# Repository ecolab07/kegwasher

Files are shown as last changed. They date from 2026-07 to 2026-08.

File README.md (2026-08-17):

# Keg Washer — Automatic Keg Cleaning Machine

> 🇫🇷 [Version française](docs/FR/README_FR.md)

An open-source automatic keg washer controller built on Arduino Uno. Cleans stainless steel kegs **without removing the spears**, using hot caustic soda and peracetic acid circulated by a pump through wash heads.

This project is a fork of [vieuxsinge/kegwasher](https://github.com/vieuxsinge/kegwasher) and [Gummy35/kegwasher](https://github.com/Gummy35/kegwasher). Licensed under [GNU GPL v3](LICENSE).

---

## What it does

The machine automates the full keg cleaning sequence:

- Initial drain and rinse
- Detergent circulation (caustic soda at 80 °C, 3 passes)
- Intermediate rinse
- Sanitizer circulation (peracetic acid, 3 passes)
- Final rinse + CO₂ purge and pressurisation

A full wash cycle takes approximately **5 minutes 30 seconds**. The machine can wash **2 kegs simultaneously**.

📷 *[Photo: machine overview]*

---

## Features

- 11 selectable wash programs via rotary encoder menu
- I²C LCD display: mode name, current step, elapsed / total time
- EEPROM persistence of last selected mode across power cycles
- LED heartbeat and buzzer end-of-cycle notification
- Actuator test mode: fires each valve individually for wiring verification
- Emergency stop via contactor (mushroom-head button)

---

## Hardware

| Component | Details |
|---|---|
| Controller | Arduino Uno (ATmega328P) |
| Relay board | 16-channel, active-low, 12 V |
| Solenoid valves | 9 × 12 V |
| Pump | Novax 20B (or equivalent) |
| Heater | 2500 W immersion element |
| Thermostat | STC1000 |
| SSR | 40 A + heatsink + 12 V fan |
| Display | I²C LCD 16×2 |
| Encoder | Rotary encoder (A1/A2) + action button (A3) |

---

## Try it in the browser

A complete Wokwi simulation is available — no hardware required:

**[▶ Open simulation](https://wokwi.com/projects/464738080652364801)**

Solenoid valves are represented by labelled LEDs. The full sketch runs without modification. Note: Wokwi simulates time slower than real speed.

---

## Repository structure

```
/
├── kegwasher.ino               — Arduino firmware (main branch)
├── CHANGELOG.md                — Fork history and change log
├── CONTRIBUTING.md             — How to contribute
├── LICENSE                     — GNU GPL v3
│
├── docs/
│   ├── EN/
│   │   ├── USER_MANUAL.md      — Operating instructions
│   │   ├── README_TECHNICAL.md — Firmware design decisions
│   │   ├── ELECTRONICS_HOWTO.md— Wiring and assembly guide
│   │   ├── MAINTENANCE_GUIDE.md— Maintenance schedule and procedures
│   │   └── GRAFCET_ALL_MODES.md— Actuator sequence diagrams (all modes)
│   └── FR/
│       ├── README_FR.md
│       ├── MANUEL_UTILISATION.md
│       ├── README_TECHNIQUE.md
│       ├── GUIDE_ELECTRONIQUE.md
│       ├── GUIDE_ENTRETIEN.md
│       └── GRAFCET_TOUS_MODES.md
│
├── fritzing/
│   ├── kegwasher.fzz           — Fritzing source file
│   └── kegwasher.png           — Wiring diagram
│
└── Images/                     — Photos and illustrations
```

---

## Documentation

| Document | EN | FR |
|---|---|---|
| User manual | [EN](docs/EN/USER_MANUAL.md) | [FR](docs/FR/MANUEL_UTILISATION.md) |
| Technical README | [EN](docs/EN/README_TECHNICAL.md) | [FR](docs/FR/README_TECHNIQUE.md) |
| Electronics assembly guide | [EN](docs/EN/ELECTRONICS_HOWTO.md) | [FR](docs/FR/GUIDE_ELECTRONIQUE.md) |
| Maintenance guide | [EN](docs/EN/MAINTENANCE_GUIDE.md) | [FR](docs/FR/GUIDE_ENTRETIEN.md) |
| Mode sequence diagrams | [EN](docs/EN/GRAFCET_ALL_MODES.md) | [FR](docs/FR/GRAFCET_TOUS_MODES.md) |

---

## Fork history

| Generation | Author | Contributions |
|---|---|---|
| v1 | [vieuxsinge](https://github.com/vieuxsinge/kegwasher) | Original project: step engine, bitmask model, wash programs, state machine |
| v2 | [Gummy35](https://github.com/Gummy35/kegwasher) | Ordered actuator sequencing, LCD alternating display, new modes, CO₂ pressurisation |
| v3 | [ecolab07](https://github.com/ecolab07/kegwasher) | Test mode, minimal transition logic, timing fixes, type safety, hardware improvements |

See [CHANGELOG.md](CHANGELOG.md) for the full detailed history.

---

## Contributing

See [CONTRIBUTING.md](CONTRIBUTING.md). Issues and pull requests are welcome.

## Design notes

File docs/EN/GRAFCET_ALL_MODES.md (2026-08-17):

# Mode Sequence Diagrams — Keg Washer

One diagram per mode. Left column "Actuators used" (no border, mirrored vertically) + right column "Steps" (normal boxes). Identical repeated cycles are grouped in a subgraph (e.g. "Detergent cycle") rather than duplicated visually in a loop.

Firmware reference: `MODES[]` in `kegwasher.ino`.

> For a description of each mode (use case, when to use it), see the [User Manual](USER_MANUAL.md).

## Table of Contents

1. [Wash + CO2](#1--wash--co2)
2. [Wash without CO2](#2--wash-without-co2)
3. [Detergent only](#3--detergent-only)
4. [CO2](#4--co2)
5. [Sanitization + CO2](#5--sanitization--co2)
6. [Keg drain](#6--keg-drain)
7. [Sanitizer drain](#7--sanitizer-drain)
8. [Detergent drain](#8--detergent-drain)
9. [Sanitizer fill](#9--sanitizer-fill)
10. [Detergent fill](#10--detergent-fill)
11. [Valve test](#11--valve-test)

---

## 1 — Wash + CO2

Source: `STEPS_WASH_KEG_PRESSURIZE` — ≈ 5 min 35

```mermaid
flowchart TD
    subgraph ACTUATORS["Actuators used"]
    direction TD
        A(["Actuators<br/>at rest"])
        B("DRAIN")
        C("PUMP&nbsp;+&nbsp;WATER&nbsp;+&nbsp;DRAIN<br/>AIR&nbsp;+&nbsp;DRAIN")
        D("PUMP&nbsp;+&nbsp;WATER&nbsp;+&nbsp;DRAIN<br/>CO2&nbsp;+&nbsp;DRAIN<br/>CO2")
        E(["Actuators<br/>at rest"])
        subgraph CL["&nbsp;"]
            direction TB
            CL1("PUMP&nbsp;+&nbsp;CLEANER_IN&nbsp;+&nbsp;CLEANER_OUT<br/>AIR&nbsp;+&nbsp;CLEANER_OUT")
            CL2("PUMP&nbsp;+&nbsp;CLEANER_IN&nbsp;+&nbsp;CLEANER_OUT<br/>AIR&nbsp;+&nbsp;CLEANER_OUT")
            CL3("PUMP&nbsp;+&nbsp;CLEANER_IN&nbsp;+&nbsp;CLEANER_OUT<br/>AIR&nbsp;+&nbsp;CLEANER_OUT")
            CL1 ~~~ CL2 ~~~ CL3
        end
        subgraph RI["&nbsp;"]
            direction TB
            RI1("PUMP&nbsp;+&nbsp;WATER&nbsp;+&nbsp;DRAIN<br/>AIR&nbsp;+&nbsp;DRAIN")
            RI2("PUMP&nbsp;+&nbsp;WATER&nbsp;+&nbsp;DRAIN<br/>AIR&nbsp;+&nbsp;DRAIN")
            RI3("PUMP&nbsp;+&nbsp;WATER&nbsp;+&nbsp;DRAIN<br/>AIR&nbsp;+&nbsp;DRAIN")
            RI1 ~~~ RI2 ~~~ RI3
        end
        subgraph SA["&nbsp;"]
            direction TB
            SA1("PUMP&nbsp;+&nbsp;SANITIZER_IN&nbsp;+&nbsp;SANITIZER_OUT<br/>AIR&nbsp;+&nbsp;SANITIZER_OUT")
            SA2("PUMP&nbsp;+&nbsp;SANITIZER_IN&nbsp;+&nbsp;SANITIZER_OUT<br/>AIR&nbsp;+&nbsp;SANITIZER_OUT")
            SA3("PUMP&nbsp;+&nbsp;SANITIZER_IN&nbsp;+&nbsp;SANITIZER_OUT<br/>AIR&nbsp;+&nbsp;SANITIZER_OUT")
            SA1 ~~~ SA2 ~~~ SA3
        end
        A ~~~ |&nbsp;| B ~~~ C
        C ~~~ CL1
        CL3 ~~~ RI1
        RI3 ~~~ SA1
        SA3 ~~~ D
        D ~~~ E
    end
    style ACTUATORS fill:none,stroke:none
    style CL fill:none,stroke:none
    style RI fill:none,stroke:none
    style SA fill:none,stroke:none
    style B fill:none,stroke:none
    style C fill:none,stroke:none
    style D fill:none,stroke:none
    style CL1 fill:none,stroke:none
    style CL2 fill:none,stroke:none
    style CL3 fill:none,stroke:none
    style RI1 fill:none,stroke:none
    style RI2 fill:none,stroke:none
    style RI3 fill:none,stroke:none
    style SA1 fill:none,stroke:none
    style SA2 fill:none,stroke:none
    style SA3 fill:none,stroke:none
    subgraph STEPS["Mode Wash + CO2"]
        direction TB
        Start(["Mode selected<br/>Wash + CO₂"])
        Drain["Drain 10 s"]
        Rinse0["Initial rinse 10 s<br/>Purge 20 s"]
        subgraph CLEAN["Detergent cycle"]
            direction TB
            C1["Detergent 10 s<br/>Purge 15 s"]
            C2["Detergent 10 s<br/>Purge 15 s"]
            C3["Detergent 10 s<br/>Purge 20 s"]
            C1 --> C2 --> C3
        end
        subgraph RINSE["Intermediate rinse"]
            direction TB
            R1["Rinse 3 s<br/>Purge 10 s"]
            R2["Rinse 7 s<br/>Purge 10 s"]
            R3["Rinse 10 s<br/>Purge 20 s"]
            R1 --> R2 --> R3
        end
        subgraph SAN["Sanitization cycle"]
            direction TB
            S1["Sanitizer 10 s<br/>Purge 15 s"]
            S2["Sanitizer 10 s<br/>Purge 15 s"]
            S3["Sanitizer 30 s<br/>Purge 20 s"]
            S1 --> S2 --> S3
        end
        Final["Final rinse 10 s<br/>CO2 purge 30 s<br/>CO2 pressurisation 10 s"]
        End(["Cycle complete<br/>3 beeps"])
        Start -->|Button press| Drain
        Drain --> Rinse0
        Rinse0 --> C1
        C3 --> R1
        R3 --> S1
        S3 --> Final
        Final --> End
    end
```

---

## 2 — Wash without CO2

Source: `STEPS_WASH_KEG` — ≈ 5 min 25

```mermaid
flowchart TD
    subgraph ACTUATORS["Actuators used"]
    direction TD
        A(["Actuators<br/>at rest"])
        B("DRAIN")
        C("PUMP&nbsp;+&nbsp;WATER&nbsp;+&nbsp;DRAIN<br/>AIR&nbsp;+&nbsp;DRAIN")
        D("PUMP&nbsp;+&nbsp;WATER&nbsp;+&nbsp;DRAIN<br/>AIR&nbsp;+&nbsp;DRAIN")
        E(["Actuators<br/>at rest"])
        subgraph CL["&nbsp;"]
            direction TB
            CL1("PUMP&nbsp;+&nbsp;CLEANER_IN&nbsp;+&nbsp;CLEANER_OUT<br/>AIR&nbsp;+&nbsp;CLEANER_OUT")
            CL2("PUMP&nbsp;+&nbsp;CLEANER_IN&nbsp;+&nbsp;CLEANER_OUT<br/>AIR&nbsp;+&nbsp;CLEANER_OUT")
            CL3("PUMP&nbsp;+&nbsp;CLEANER_IN&nbsp;+&nbsp;CLEANER_OUT<br/>AIR&nbsp;+&nbsp;CLEANER_OUT")
            CL1 ~~~ CL2 ~~~ CL3
        end
        subgraph RI["&nbsp;"]
            direction TB
            RI1("PUMP&nbsp;+&nbsp;WATER&nbsp;+&nbsp;DRAIN<br/>AIR&nbsp;+&nbsp;DRAIN")
            RI2("PUMP&nbsp;+&nbsp;WATER&nbsp;+&nbsp;DRAIN<br/>AIR&nbsp;+&nbsp;DRAIN")
            RI3("PUMP&nbsp;+&nbsp;WATER&nbsp;+&nbsp;DRAIN<br/>AIR&nbsp;+&nbsp;DRAIN")
            RI1 ~~~ RI2 ~~~ RI3
        end
        subgraph SA["&nbsp;"]
            direction TB
            SA1("PUMP&nbsp;+&nbsp;SANITIZER_IN&nbsp;+&nbsp;SANITIZER_OUT<br/>AIR&nbsp;+&nbsp;SANITIZER_OUT")
            SA2("PUMP&nbsp;+&nbsp;SANITIZER_IN&nbsp;+&nbsp;SANITIZER_OUT<br/>AIR&nbsp;+&nbsp;SANITIZER_OUT")
            SA3("PUMP&nbsp;+&nbsp;SANITIZER_IN&nbsp;+&nbsp;SANITIZER_OUT<br/>AIR&nbsp;+&nbsp;SANITIZER_OUT")
            SA1 ~~~ SA2 ~~~ SA3
        end
        A ~~~ |&nbsp;| B ~~~ C
        C ~~~ CL1
        CL3 ~~~ RI1
        RI3 ~~~ SA1
        SA3 ~~~ D
        D ~~~ E
    end
    style ACTUATORS fill:none,stroke:none
    style CL fill:none,stroke:none
    style RI fill:none,stroke:none
    style SA fill:none,stroke:none
    style B fill:none,stroke:none
    style C fill:none,stroke:none
    style D fill:none,stroke:none
    style CL1 fill:none,stroke:none
    style CL2 fill:none,stroke:none
    style CL3 fill:none,stroke:none
    style RI1 fill:none,stroke:none
    style RI2 fill:none,stroke:none
    style RI3 fill:none,stroke:none
    style SA1 fill:none,stroke:none
    style SA2 fill:none,stroke:none
    style SA3 fill:none,stroke:none
    subgraph STEPS["Mode Wash without CO2"]
        direction TB
        Start(["Mode selected<br/>Wash without CO₂"])
        Drain["Drain 10 s"]
        Rinse0["Initial rinse 10 s<br/>Purge 20 s"]
        subgraph CLEAN["Detergent cycle"]
            direction TB
            C1["Detergent 10 s<br/>Purge 15 s"]
            C2["Detergent 10 s<br/>Purge 15 s"]
            C3["Detergent 10 s<br/>Purge 20 s"]
            C1 --> C2 --> C3
        end
        subgraph RINSE["Intermediate rinse"]
            direction TB
            R1["Rinse 3 s<br/>Purge 10 s"]
            R2["Rinse 7 s<br/>Purge 10 s"]
            R3["Rinse 10 s<br/>Purge 20 s"]
            R1 --> R2 --> R3
        end
        subgraph SAN["Sanitization cycle"]
            direction TB
            S1["Sanitizer 10 s<br/>Purge 15 s"]
            S2["Sanitizer 10 s<br/>Purge 15 s"]
            S3["Sanitizer 30 s<br/>Purge 20 s"]
            S1 --> S2 --> S3
        end
        Final["Final rinse 10 s<br/>Air purge 30 s"]
        End(["Cycle complete<br/>3 beeps"])
        Start -->|Button press| Drain
        Drain --> Rinse0
        Rinse0 --> C1
        C3 --> R1
        R3 --> S1
        S3 --> Final
        Final --> End
    end
```

---

## 3 — Detergent only

Source: `STEPS_DETER_KEG` — ≈ 3 min 00. No sanitization cycle, no separate final rinse: the intermediate rinse cycle ends the mode directly.

```mermaid
flowchart TD
    subgraph ACTUATORS["Actuators used"]
    direction TD
        A(["Actuators<br/>at rest"])
        B("DRAIN")
        C("PUMP&nbsp;+&nbsp;WATER&nbsp;+&nbsp;DRAIN<br/>AIR&nbsp;+&nbsp;DRAIN")
        E(["Actuators<br/>at rest"])
        subgraph CL["&nbsp;"]
            direction TB
            CL1("PUMP&nbsp;+&nbsp;CLEANER_IN&nbsp;+&nbsp;CLEANER_OUT<br/>AIR&nbsp;+&nbsp;CLEANER_OUT")
            CL2("PUMP&nbsp;+&nbsp;CLEANER_IN&nbsp;+&nbsp;CLEANER_OUT<br/>AIR&nbsp;+&nbsp;CLEANER_OUT")
            CL3("PUMP&nbsp;+&nbsp;CLEANER_IN&nbsp;+&nbsp;CLEANER_OUT<br/>AIR&nbsp;+&nbsp;CLEANER_OUT")
            CL1 ~~~ CL2 ~~~ CL3
        end
        subgraph RI["&nbsp;"]
            direction TB
            RI1("PUMP&nbsp;+&nbsp;WATER&nbsp;+&nbsp;DRAIN<br/>AIR&nbsp;+&nbsp;DRAIN")
            RI2("PUMP&nbsp;+&nbsp;WATER&nbsp;+&nbsp;DRAIN<br/>AIR&nbsp;+&nbsp;DRAIN")
            RI3("PUMP&nbsp;+&nbsp;WATER&nbsp;+&nbsp;DRAIN<br/>AIR&nbsp;+&nbsp;DRAIN")
            RI1 ~~~ RI2 ~~~ RI3
        end
        A ~~~ |&nbsp;| B ~~~ C
        C ~~~ CL1
        CL3 ~~~ RI1
        RI3 ~~~ E
    end
    style ACTUATORS fill:none,stroke:none
    style CL fill:none,stroke:none
    style RI fill:none,stroke:none
    style B fill:none,stroke:none
    style C fill:none,stroke:none
    style CL1 fill:none,stroke:none
    style CL2 fill:none,stroke:none
    style CL3 fill:none,stroke:none
    style RI1 fill:none,stroke:none
    style RI2 fill:none,stroke:none
    style RI3 fill:none,stroke:none
    subgraph STEPS["Mode Detergent only"]
        direction TB
        Start(["Mode selected<br/>Detergent only"])
        Drain["Drain 10 s"]
        Rinse0["Initial rinse 10 s<br/>Purge 20 s"]
        subgraph CLEAN["Detergent cycle"]
            direction TB
            C1["Detergent 10 s<br/>Purge 15 s"]
            C2["Detergent 10 s<br/>Purge 15 s"]
            C3["Detergent 10 s<br/>Purge 20 s"]
            C1 --> C2 --> C3
        end
        subgraph RINSE["Intermediate rinse"]
            direction TB
            R1["Rinse 3 s<br/>Purge 10 s"]
            R2["Rinse 7 s<br/>Purge 10 s"]
            R3["Rinse 10 s<br/>Purge 20 s"]
            R1 --> R2 --> R3
        end
        End(["Cycle complete<br/>3 beeps"])
        Start -->|Button press| Drain
        Drain --> Rinse0
        Rinse0 --> C1
        C3 --> R1
        R3 --> End
    end
```

---

## 4 — CO2

Source: `STEPS_KEG_PRESSURIZE` — 50 s. Shortest mode, purely linear.

```mermaid
flowchart TD
    subgraph ACTUATORS["Actuators used"]
    direction TD
        A(["Actuators<br/>at rest"])
        B("DRAIN")
        C("CO2&nbsp;+&nbsp;DRAIN")
        D("CO2")
        E(["Actuators<br/>at rest"])
        A ~~~ |&nbsp;| B ~~~ C ~~~ D ~~~ E
    end
    style ACTUATORS fill:none,stroke:none
    style B fill:none,stroke:none
    style C fill:none,stroke:none
    style D fill:none,stroke:none
    subgraph STEPS["Mode CO2"]
        direction TB
        Start(["Mode selected<br/>CO2"])
        Drain["Drain 10 s"]
        Purge["CO2 purge 30 s"]
        Press["CO2 pressurisation 10 s"]
        End(["Cycle complete<br/>3 beeps"])
        Start -->|Button press| Drain
        Drain --> Purge
        Purge --> Press
        Press --> End
    end
```

---

## 5 — Sanitization + CO2

Source: `STEPS_SANITIZE_KEG_PRESSURIZE` — ≈ 3 min 10

```mermaid
flowchart TD
    subgraph ACTUATORS["Actuators used"]
    direction TD
        A(["Actuators<br/>at rest"])
        B("DRAIN")
        C("PUMP&nbsp;+&nbsp;WATER&nbsp;+&nbsp;DRAIN<br/>AIR&nbsp;+&nbsp;DRAIN")
        D("PUMP&nbsp;+&nbsp;WATER&nbsp;+&nbsp;DRAIN<br/>CO2&nbsp;+&nbsp;DRAIN<br/>CO2")
        E(["Actuators<br/>at rest"])
        subgraph SA["&nbsp;"]
            direction TB
            SA1("PUMP&nbsp;+&nbsp;SANITIZER_IN&nbsp;+&nbsp;SANITIZER_OUT<br/>AIR&nbsp;+&nbsp;SANITIZER_OUT")
            SA2("PUMP&nbsp;+&nbsp;SANITIZER_IN&nbsp;+&nbsp;SANITIZER_OUT<br/>AIR&nbsp;+&nbsp;SANITIZER_OUT")
            SA3("PUMP&nbsp;+&nbsp;SANITIZER_IN&nbsp;+&nbsp;SANITIZER_OUT<br/>AIR&nbsp;+&nbsp;SANITIZER_OUT")
            SA1 ~~~ SA2 ~~~ SA3
        end
        A ~~~ |&nbsp;| B ~~~ C
        C ~~~ SA1
        SA3 ~~~ D
        D ~~~ E
    end
    style ACTUATORS fill:none,stroke:none
    style SA fill:none,stroke:none
    style B fill:none,stroke:none
    style C fill:none,stroke:none
    style D fill:none,stroke:none
    style SA1 fill:none,stroke:none
    style SA2 fill:none,stroke:none
    style SA3 fill:none,stroke:none
    subgraph STEPS["Mode Sanitization + CO2"]
        direction TB
        Start(["Mode selected<br/>Sanitiz. + CO₂"])
        Drain["Drain 10 s"]
        Rinse0["Initial rinse 10 s<br/>Purge 20 s"]
        subgraph SAN["Sanitization cycle"]
            direction TB
            S1["Sanitizer 10 s<br/>Purge 15 s"]
            S2["Sanitizer 10 s<br/>Purge 15 s"]
            S3["Sanitizer 30 s<br/>Purge 20 s"]
            S1 --> S2 --> S3
        end
        Final["Final rinse 10 s<br/>CO2 purge 30 s<br/>CO2 pressurisation 10 s"]
        End(["Cycle complete<br/>3 beeps"])
        Start -->|Button press| Drain
        Drain --> Rinse0
        Rinse0 --> S1
        S3 --> Final
        Final --> End
    end
```

---

## 6 — Keg drain

Source: `STEPS_DRAIN_KEG` — 70 s

```mermaid
flowchart TD
    subgraph ACTUATORS["Actuators used"]
    direction TD
        A(["Actuators<br/>at rest"])
        B("DRAIN")
        C("AIR&nbsp;+&nbsp;DRAIN")
        E(["Actuators<br/>at rest"])
        A ~~~ |&nbsp;| B ~~~ C ~~~ E
    end
    style ACTUATORS fill:none,stroke:none
    style B fill:none,stroke:none
    style C fill:none,stroke:none
    subgraph STEPS["Mode Keg drain"]
        direction TB
        Start(["Mode selected<br/>Keg drain"])
        Drain["Drain 10 s"]
        Purge["Air purge 60 s"]
        End(["Cycle complete<br/>3 beeps"])
        Start -->|Button press| Drain
        Drain --> Purge
        Purge --> End
    end
```

---

## 7 — Sanitizer drain

Source: `STEPS_DRAIN_SANITIZER` — 200 s, single step.

```mermaid
flowchart TD
    subgraph ACTUATORS["Actuators used"]
    direction TD
        A(["Actuators<br/>at rest"])
        B("PUMP&nbsp;+&nbsp;SANITIZER_IN&nbsp;+&nbsp;DRAIN")
        E(["Actuators<br/>at rest"])
        A ~~~ |&nbsp;| B ~~~ E
    end
    style ACTUATORS fill:none,stroke:none
    style B fill:none,stroke:none
    subgraph STEPS["Mode Sanitizer drain"]
        direction TB
        Start(["Mode selected<br/>Sanitizer drain"])
        Drain["Drain sanitizer tank<br/>200 s"]
        End(["Cycle complete<br/>3 beeps"])
        Start -->|Button press| Drain
        Drain --> End
    end
```

---

## 8 — Detergent drain

Source: `STEPS_DRAIN_CLEANER` — 200 s, single step.

```mermaid
flowchart TD
    subgraph ACTUATORS["Actuators used"]
    direction TD
        A(["Actuators<br/>at rest"])
        B("PUMP&nbsp;+&nbsp;CLEANER_IN&nbsp;+&nbsp;DRAIN")
        E(["Actuators<br/>at rest"])
        A ~~~ |&nbsp;| B ~~~ E
    end
    style ACTUATORS fill:none,stroke:none
    style B fill:none,stroke:none
    subgraph STEPS["Mode Detergent drain"]
        direction TB
        Start(["Mode selected<br/>Detergent drain"])
        Drain["Drain detergent tank<br/>200 s"]
        End(["Cycle complete<br/>3 beeps"])
        Start -->|Button press| Drain
        Drain --> End
    end
```

---

## 9 — Sanitizer fill

Source: `STEPS_FILL_SANITIZER` — 120 s, single step.

```mermaid
flowchart TD
    subgraph ACTUATORS["Actuators used"]
    direction TD
        A(["Actuators<br/>at rest"])
        B("PUMP&nbsp;+&nbsp;SANITIZER_OUT&nbsp;+&nbsp;WATER")
        E(["Actuators<br/>at rest"])
        A ~~~ |&nbsp;| B ~~~ E
    end
    style ACTUATORS fill:none,stroke:none
    style B fill:none,stroke:none
    subgraph STEPS["Mode Sanitizer fill"]
        direction TB
        Start(["Mode selected<br/>Sanitizer fill"])
        Fill["Fill sanitizer tank<br/>120 s"]
        End(["Cycle complete<br/>3 beeps"])
        Start -->|Button press| Fill
        Fill --> End
    end
```

---

## 10 — Detergent fill

Source: `STEPS_FILL_CLEANER` — 120 s, single step.

```mermaid
flowchart TD
    subgraph ACTUATORS["Actuators used"]
    direction TD
        A(["Actuators<br/>at rest"])
        B("PUMP&nbsp;+&nbsp;CLEANER_OUT&nbsp;+&nbsp;WATER")
        E(["Actuators<br/>at rest"])
        A ~~~ |&nbsp;| B ~~~ E
    end
    style ACTUATORS fill:none,stroke:none
    style B fill:none,stroke:none
    subgraph STEPS["Mode Detergent fill"]
        direction TB
        Start(["Mode selected<br/>Detergent fill"])
        Fill["Fill detergent tank<br/>120 s"]
        End(["Cycle complete<br/>3 beeps"])
        Start -->|Button press| Fill
        Fill --> End
    end
```

---

## 11 — Valve test

Source: `STEPS_TEST_ACTUATORS` — 24 s.

**Template exception:** this mode does not follow the two-column layout. Each step activates a *different* actuator (no repeated identical block), so the "Actuators" column would be redundant with the step name itself. Single-column diagram, purely sequential.

```mermaid
flowchart TD
    subgraph STEPS["Mode Valve test"]
        direction TB
        Start(["Mode selected<br/>Valve test"])
        Warn{{"Confirmation:<br/>tanks empty?<br/>5 s"}}
        T1["Sanitizer return valve<br/>1 s"]
        T2["Drain valve<br/>1 s"]
        T3["Cleaner return valve<br/>1 s"]
        T4["Air valve<br/>1 s"]
        T5["CO2 valve<br/>1 s"]
        T6["Sanitizer inlet valve<br/>1 s"]
        T7["Water valve<br/>1 s"]
        T8["Cleaner inlet valve<br/>1 s"]
        T9["Pump<br/>1 s"]
        End(["Cycle complete<br/>3 beeps"])
        Start -->|Button press| Warn
        Warn -->|1 s gap| T1
        T1 -->|1 s gap| T2
        T2 -->|1 s gap| T3
        T3 -->|1 s gap| T4
        T4 -->|1 s gap| T5
        T5 -->|1 s gap| T6
        T6 -->|1 s gap| T7
        T7 -->|1 s gap| T8
        T8 -->|1 s gap| T9
        T9 --> End
    end
```

**Note valid for all 11 modes:** pressing the button during execution cancels the running sequence (valves close, 1 beep, return to selection screen) — not shown on each diagram to avoid clutter.

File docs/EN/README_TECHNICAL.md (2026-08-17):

# kegwasher — Technical README

> This project is a fork of [vieuxsinge/kegwasher](https://github.com/vieuxsinge/kegwasher)
> and [Gummy35/kegwasher](https://github.com/Gummy35/kegwasher).
> License: GNU GPL v3.

This document covers the technical design decisions made across the three generations of the project. For usage instructions, see [USER_MANUAL.md](USER_MANUAL.md).

---

## Table of Contents

1. [Architecture overview](#1-architecture-overview)
2. [Step-based sequence engine](#2-step-based-sequence-engine)
3. [Actuator control model](#3-actuator-control-model)
4. [Ordered open/close sequencing — Gummy35 + Ecolab07](#4-ordered-openclose-sequencing--gummy35--ecolab07)
5. [Pin pre-initialisation to HIGH — Ecolab07](#5-pin-pre-initialisation-to-high--ecolab07)
6. [State machine](#6-state-machine)
7. [LCD display: alternating step and mode labels — Gummy35 + Ecolab07](#7-lcd-display-alternating-step-and-mode-labels--gummy35--ecolab07)
8. [Rotary encoder: negative value guard — Ecolab07](#8-rotary-encoder-negative-value-guard--ecolab07)
9. [EEPROM persistence of selected mode](#9-eeprom-persistence-of-selected-mode)
10. [Actuator test mode — Ecolab07](#10-actuator-test-mode--ecolab07)
11. [Wash mode catalogue](#11-wash-mode-catalogue)
12. [Hardware notes](#12-hardware-notes)
13. [Dependencies](#13-dependencies)
14. [Wokwi simulation](#14-wokwi-simulation)
15. [Wiring diagram (Fritzing)](#15-wiring-diagram-fritzing)
16. [Known limitations and future work](#16-known-limitations-and-future-work)

---

## 1. Architecture overview

The firmware is a single `.ino` file structured around three independent layers:

```
┌─────────────────────────────────┐
│  Mode table  (MODES[])          │  Named modes → step arrays
├─────────────────────────────────┤
│  Sequence engine                │  Steps → actuator configs + timing
├─────────────────────────────────┤
│  Actuator control layer         │  Bitmasks → individual GPIO writes
└─────────────────────────────────┘
```

Adding a new wash program requires only a new `step_t` array and one entry in `MODES[]`. No control logic needs to change.

---

## 2. Step-based sequence engine

Each wash program is expressed as an array of `step_t` structs:

```c
typedef struct step_s {
  unsigned int  config;   // bitmask of actuators to activate
  unsigned long duration; // how long to hold this configuration (seconds)
} step_t;
```

The array is terminated by the sentinel value `{CONFIG_END, 0}` (where `CONFIG_END == 0`), which is how `run_update()` detects end-of-sequence without needing a length parameter.

At runtime, `step_set(index)` applies the valve configuration via `controls_set()` (blocking), then records `step_start_time` after the transitions complete. `run_update()` is called on every `loop()` iteration and advances to the next step as soon as `seconds() - step_start_time >= step.duration`.

Recording `step_start_time` after the transitions ensures each step's declared duration is measured from when the valves are actually in their target state, not from before the blocking delay. The same principle applies to `mode_start_time`, which is recorded after `step_set(0)` in `run()`.

Using wall-clock seconds (via `millis() / 1000`) rather than a counter makes step timing independent of loop execution time. All time variables use `unsigned long` (32 bits on AVR), consistent with `millis()` and safe from the 16-bit overflow that would affect `int` after ~9 hours.

---

## 3. Actuator control model

Each of the 9 physical outputs is assigned a unique power-of-two bit:

```c
#define CTRL_WATER          0b000000001
#define CTRL_CLEANER_IN     0b000000010
#define CTRL_SANITIZER_IN   0b000000100
#define CTRL_AIR            0b000001000
#define CTRL_CO2            0b000010000
#define CTRL_DRAIN          0b000100000
#define CTRL_CLEANER_OUT    0b001000000
#define CTRL_SANITIZER_OUT  0b010000000
#define CTRL_PUMP           0b100000000
```

Composite configurations for the wash sequences are built by OR-ing individual bits:

```c
#define CONFIG_CLEAN  (CTRL_PUMP + CTRL_CLEANER_IN + CTRL_CLEANER_OUT)
```

This gives a compact, readable, and easily extensible representation. Adding a 10th actuator only requires a new bit and a new pin — no structural changes.

The test mode deliberately uses raw `CTRL_*` bits (one actuator at a time) rather than composite `CONFIG_*` values, which is what makes it useful for diagnosing individual valve behaviour.

---

## 4. Ordered open/close sequencing — *Gummy35* + *Ecolab07*

The original firmware switched all actuators simultaneously with no delay between them, using raw `HIGH`/`LOW` values. Gummy35 refactored `controls_set_state()` entirely, introducing three changes.

**Named logic constants** replacing raw `HIGH`/`LOW`:
```c
#define VALVE_CLOSE HIGH
#define VALVE_OPEN  LOW
```
This makes the active-low relay logic explicit at every call site.

**Per-direction ordering** — actuators are now opened and closed in a carefully chosen order:

Closing order (pressure sources first, then outputs): pump → water/CO₂/air → liquid inlets → return paths → drain (last, so residual pressure can escape).

Opening order (clear path before pressure): drain/returns → liquid inlets → pump (draws liquid, reducing inlet pressure) → air → CO₂ → water (last — pump backpressure prevents back-flow into tanks).

This ordering prevents pressure spikes trapping liquid in lines when closing, water or chemicals back-flowing into CO₂ or air lines when opening, and pump cavitation.

**Inter-actuator delay on closing** increased from 0 ms to 200 ms, matching the opening delay already present in the original:

```c
// before (Vieuxsinge)
controls_set_state(~config, HIGH, 0);   // close: no delay
controls_set_state(config,  LOW,  200); // open:  200 ms

// after (Gummy35)
controls_set_state(~config, VALVE_CLOSE, 200); // close: 200 ms
controls_set_state(config,  VALVE_OPEN,  200); // open:  200 ms
```

**Also changed by Gummy35**: `CONFIG_FILL_SANITIZER` and `CONFIG_FILL_CLEANER` had `CTRL_PUMP` removed (filling by mains pressure only). This was reverted in the ecolab07 fork — the pump is needed to circulate water through the keg and back into the tank via the return valves (`CTRL_SANITIZER_OUT` / `CTRL_CLEANER_OUT`). The inlet valves (`CTRL_SANITIZER_IN` / `CTRL_CLEANER_IN`) are oriented in the wrong direction for this flow path and are not used during filling.

**Ecolab07 — minimal transition logic**: `controls_set_state()` was split into `close_actuators()` and `open_actuators()`, and `controls_set()` was rewritten to only touch actuators that actually change state:

```c
unsigned int previous_config = 0;  // tracks the active configuration

void controls_set(unsigned int config)
{
  unsigned int to_close = previous_config & ~config;
  unsigned int to_open  = config & ~previous_config;

  close_actuators(to_close);
  open_actuators(to_open);

  previous_config = config;
}
```

`previous_config & ~config` isolates actuators that were open and are no longer needed. `config & ~previous_config` isolates actuators that are needed and were not already open. Actuators that appear in both the old and new configuration are not touched. This has three benefits:

- **Inrush current**: only the relays that actually change state switch, never all 9 simultaneously.
- **Timing accuracy**: the 200 ms delay only applies to actuators that move, so transitions between similar configurations (e.g. `CONFIG_CLEAN` → `CONFIG_CLEAN_PURGE`, which share `CTRL_CLEANER_OUT`) are faster.
- **`CONFIG_WARNING` / `CONFIG_WAIT` safety by design**: these pseudo-configs have bits 10 and 11 set, outside the 9-bit actuator range. `to_close` and `to_open` mask these bits out naturally — no actuator is ever triggered, regardless of what `previous_config` held.

---

## 5. Pin pre-initialisation to HIGH — *Ecolab07*

The relay board uses **active-low logic**: a LOW signal on a control pin energises the relay and opens the valve. The Arduino's GPIO pins default to a high-impedance input state at power-up, which the relay board pulls LOW — briefly energising all relays before `pinMode(OUTPUT)` is called in `setup()`.

This causes an uncontrolled inrush current spike (all 9 relays switching simultaneously) and, more critically, a momentary opening of all valves.

The fix is to write `HIGH` to each pin *before* calling `pinMode()`:

```c
// Pre-drive HIGH before configuring as output to prevent
// the brief LOW glitch that would otherwise energise all relays at power-up
digitalWrite(PIN_VALVE_AIR, HIGH);
// ... all other valve and pump pins ...
pinMode(PIN_VALVE_AIR, OUTPUT);
// ...
```

On AVR-based Arduinos, `digitalWrite()` on a pin that is still in input mode writes to the pull-up register, which does not produce a LOW glitch. The transition to `OUTPUT` mode therefore starts from a committed HIGH level, keeping all relays de-energised.

---

## 6. State machine

The main loop dispatches on a `state_t` enum:

```
STATE_SELECT → STATE_SELECT_UPDATE ──────────────────────┐
                     │ (button press)                     │
                     ▼                                    │
               STATE_RUN                                  │
                     │                                    │
                     ▼                                    │
             STATE_RUN_UPDATE ──── (button press) ──► STATE_CANCEL ─┐
                     │ (CONFIG_END)                                  │
                     ▼                                               │
             STATE_TERMINATE ──────────────────────────────────────►┘
                                                         (all → STATE_SELECT)
```

Each state has a dedicated handler function. Transitions are written as assignments to the global `state` variable, which the next `loop()` iteration will dispatch on. This keeps each handler small and single-purpose.

---

## 7. LCD display: alternating step and mode labels — *Gummy35* + *Ecolab07*

During a running cycle, line 1 of the LCD alternates between two pieces of information on a `LED_BLINK_PERIOD` (2 s) cadence:

- **First half of period**: the current step label — e.g. `Detergent`, `Purge air`
- **Second half of period**: the mode name — e.g. `Lavage + CO2`

The LED blinks in sync with this alternation, providing a visible heartbeat that also confirms the Arduino is still running.

```c
if( mode_running_time % LED_BLINK_PERIOD < LED_BLINK_PERIOD/2 ) {
    digitalWrite(PIN_LED, HIGH);
    lcd.setCursor(0, 0);
    lcd_printf(resolve_label(MODES[mode].steps[step].config));
}
else {
    digitalWrite(PIN_LED, LOW);
    lcd.setCursor(0, 0);
    lcd_printf(MODES[mode].name);
}
```

**Gummy35** introduced this alternating display and resolved labels via a `config_label` global variable written inside `controls_set_state()`. **Ecolab07** replaced this with `resolve_label()`, a pure function that returns a `const char*` to a Flash literal with no side effects. The global variable is eliminated — the label is resolved on demand directly from the current step's config.

---

## 8. Rotary encoder: negative value guard — *Ecolab07*

The `RotaryEncoder` library returns a signed integer position that decrements below zero when the encoder is turned counter-clockwise past position 0. A naive modulo operation in C produces negative results for negative operands (the sign follows the dividend), which would result in an invalid array index into `MODES[]`.

**First approach** — adding `MODES_NUMBER` before the modulo:
```c
new_mode = (pos + MODES_NUMBER) % MODES_NUMBER;
```
This works correctly for one full counter-clockwise wrap (e.g. `pos = -3` with `MODES_NUMBER = 11` gives `8` ✅), but silently fails when `pos` is more negative than `-MODES_NUMBER` (e.g. `pos = -14` gives `-3` ❌, because `(-14 + 11) % 11 = -3` in C).

**Current approach** — double modulo:
```c
new_mode = ((pos % MODES_NUMBER) + MODES_NUMBER) % MODES_NUMBER;
```
`pos % MODES_NUMBER` first reduces any value into `(-MODES_NUMBER, MODES_NUMBER)`, then adding `MODES_NUMBER` makes it positive, and the final `% MODES_NUMBER` brings it back into `[0, MODES_NUMBER - 1]`. This is correct for any value of `pos`, regardless of how far counter-clockwise the encoder has been turned.

---

## 9. EEPROM persistence of selected mode

The index of the last selected mode is written to EEPROM address `0` when a cycle is launched (only if the value has changed, to limit write wear):

```c
int saved_mode = EEPROM.read(EEPROM_ADDRESS_MODE);
if( mode != saved_mode ) {
    EEPROM.write(EEPROM_ADDRESS_MODE, mode);
}
```

On power-up, the stored value is read and clamped to the valid range:

```c
mode = constrain(mode, 0, MODES_NUMBER - 1);
```

The clamp handles the case where the EEPROM contains `0xFF` (erased state) or a stale index from a firmware version with fewer modes.

---

## 10. Actuator test mode — *Ecolab07*

The test mode fires each of the 9 actuators individually for 1 second, in the physical order of the relay board, with a 1-second idle gap between each pulse.

**Design intent**: the test mode is implemented entirely as a `step_t` array (`STEPS_TEST_ACTUATORS`), using the same sequence engine as all other modes. No special-case code was added to the control layer.

Each step uses a raw `CTRL_*` bit rather than a composite `CONFIG_*` value, so exactly one relay clicks per step. This makes it straightforward to verify each valve by ear or by watching the circuit.

Two special pseudo-configurations are introduced exclusively for this mode:

| Constant | Bit | Role |
|---|---|---|
| `CONFIG_WARNING` | bit 10 | Displays a safety prompt (`Cuves vides ?`) before the first relay fires. No actuator is activated. |
| `CONFIG_WAIT` | bit 11 | Idle step between pulses: `controls_set(CONFIG_WAIT)` closes everything (bits 0–9 are all zero in the mask), producing a clean off state between each individual actuation. |

Both bits are outside the 9-bit range of real actuator bits, so they cannot accidentally overlap with any physical output.

---

## 11. Wash mode catalogue

| Mode | Array | Duration | Gummy35 | Ecolab07 |
|---|---|---|---|---|
| `Lavage + CO2` | `STEPS_WASH_KEG_PRESSURIZE` | 330 s | ✅ CO₂ step | |
| `Lavage sans CO2` | `STEPS_WASH_KEG` | 320 s | | |
| `Detergent seul` | `STEPS_DETER_KEG` | 180 s | ✅ added | |
| `CO2` | `STEPS_KEG_PRESSURIZE` | 50 s | ✅ added | |
| `Desinf. + CO2` | `STEPS_SANITIZE_KEG_PRESSURIZE` | 190 s | ✅ added | |
| `Vidange fut` | `STEPS_DRAIN_KEG` | 70 s | | |
| `Vidange desinf.` | `STEPS_DRAIN_SANITIZER` | 200 s | | |
| `Vidange deter.` | `STEPS_DRAIN_CLEANER` | 200 s | | |
| `Rempl. desinf.` | `STEPS_FILL_SANITIZER` | 120 s | | |
| `Rempl. deter.` | `STEPS_FILL_CLEANER` | 120 s | | |
| `Test vannes` | `STEPS_TEST_ACTUATORS` | 22 s | | ✅ added |

---

## 12. Hardware notes

### Relay board — active-low logic
The 16-channel relay board uses active-low inputs. All control pins are pre-driven HIGH at boot (see §5) to prevent unintended actuation.

### Flyback diode protection
Solenoid valves are inductive loads. Without protection, the back-EMF spike when a valve de-energises can destroy relay contacts. A 1N4148 flyback diode is placed across each valve terminal, as close to the relay output as possible.

### SSR for the detergent heater
The immersion heater in the detergent tank is switched by a 40 A solid-state relay (SSR), controlled by the STC1000 thermostat. The original 3500 W element was downrated to **2500 W** to avoid tripping the circuit breaker on shared circuits — heating is slower but stays within the breaker's sustained current rating. The SSR is fitted with a **heatsink and a 12 V cooling fan** (Ecolab07 improvement) to prevent thermal runaway during long heating sessions.

### Emergency stop via contactor
The original design connected the emergency stop button directly in the control circuit. Ecolab07 replaced this with a **contactor** driven by the mushroom-head button, so the button switches only a low-current coil rather than the full load current of the machine. This improves button longevity and is safer in a wet environment.

### Arduino terminal screw shield
Ecolab07 added a **terminal screw shield** on top of the Arduino, fitted with an integrated prototyping area. This allows:
- the LED current-limiting resistor to be mounted cleanly on the board
- all external cables to be terminated on screw terminals rather than Dupont connectors, improving mechanical reliability in an environment subject to vibration and moisture.

### Relay output bus bars
Ecolab07 added **bus bar rails** on the relay output side to simplify solenoid valve wiring. Each bus bar groups the common 12 V return wire for a set of valves, reducing point-to-point wiring complexity and making the enclosure easier to read.

### Component labelling
All components inside the enclosure are identified by adhesive labels. This makes fault-finding and maintenance accessible without referring to a wiring diagram.

---

## 13. Dependencies

| Library | Version tested | Purpose |
|---|---|---|
| `Bounce2` | any | Button debouncing |
| `LiquidCrystal_I2C` | 1.1.2 | I²C LCD driver |
| `RotaryEncoder` | any | Rotary encoder reading |

**`LiquidCrystal_I2C`** — authored by Frank de Brabander, maintained by Marco Schwartz, hosted at [github.com/johnrickman/LiquidCrystal_I2C](https://github.com/johnrickman/LiquidCrystal_I2C). Install via the Arduino IDE Library Manager by searching for `LiquidCrystal I2C` — this installs version 1.1.2, which is the version used in this project and works without modification. There are several other forks of this library under similar names; using the wrong one may cause compilation errors or incorrect display behaviour.

---

## 14. Wokwi simulation

A complete circuit simulation is available at:
**[https://wokwi.com/projects/464738080652364801](https://wokwi.com/projects/464738080652364801)**

The simulation includes the Arduino Uno, I²C LCD display, relay board (active-low logic), status LED, buzzer, rotary encoder, and action button. Solenoid valves are represented by LEDs labelled with the corresponding valve name, allowing visual verification of each actuation sequence.

The full sketch runs without modification in the simulator.

**Known Wokwi limitations vs real hardware:**
- Displayed seconds run slower than real time — Wokwi does not simulate wall-clock time at 1:1 speed, so cycle durations appear longer than declared.
- The relay board's active-low logic is simulated with inverted polarity — verify the `VALVE_OPEN`/`VALVE_CLOSE` defines match your physical relay board before flashing to real hardware.

---

## 15. Wiring diagram (Fritzing)

A detailed Fritzing wiring diagram is provided in the repository (`fritzing/kegwasher.fzz` and `fritzing/kegwasher.png`). The diagram reflects the actual physical layout of components inside the enclosure and highlights four distinct zones:

- **Deported components**: LCD display and action button wired to the front panel
- **Safety block**: emergency stop mushroom-head button and contactor
- **Power outlets**: connection points for the immersion heater and circulation pump
- **Hydraulic zone**: solenoid valve wiring and relay output bus bars

The `.fzz` source file is included for anyone who wants to modify or extend the diagram.

---

## 16. Known limitations and future work

### Displayed time vs real time
The 200 ms inter-actuator delay in `close_actuators()` and `open_actuators()` is a blocking `delay()` call. During transitions, `loop()` does not run, so displayed seconds accumulate slightly slower than real seconds. The overhead per transition is proportional to the number of actuators that change state (0–9 relays × 200 ms). For the longest modes this adds approximately 15 s of drift over a 5 min 35 s cycle.

Branch `feature/nonblocking-timers` addresses this by measuring transition duration with `millis()` and subtracting it from the displayed elapsed time.

### Rotary encoder and button polling
The encoder and button are polled in the main loop (`menuselect.tick()`, `buttonAction.update()`). During blocking transitions, button presses may be missed if they occur within a 200 ms window.

Branch `feature/rotary-interrupts` addresses this by migrating encoder and button handling to Pin Change Interrupts (PCINT), making input detection independent of loop timing.

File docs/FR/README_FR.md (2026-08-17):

# Laveuse de fûts automatique

> 🇬🇧 [English version](../../README.md)

Un contrôleur open-source de laveuse de fûts construit sur Arduino Uno. Nettoie les fûts en inox **sans démonter les plongeurs**, en faisant circuler de la soude chaude et de l'acide peracétique via des têtes de lavage.

Ce projet est un fork de [vieuxsinge/kegwasher](https://github.com/vieuxsinge/kegwasher) et de [Gummy35/kegwasher](https://github.com/Gummy35/kegwasher). Licence [GNU GPL v3](../../LICENSE).

---

## Ce que ça fait

La machine automatise le cycle complet de nettoyage des fûts :

- Vidange et rinçage initial
- Circulation de détergent (soude à 80 °C, 3 passes)
- Rinçage intermédiaire
- Circulation de désinfectant (acide peracétique, 3 passes)
- Rinçage final + purge et pressurisation CO₂

Un cycle de lavage complet dure environ **5 minutes 30 secondes**. La machine peut laver **2 fûts simultanément**.

📷 *[Photo : vue d'ensemble de la machine]*

---

## Fonctionnalités

- 11 programmes de lavage sélectionnables via un encodeur rotatif
- Afficheur LCD I²C : nom du mode, étape en cours, temps écoulé / temps total
- Mémorisation du dernier mode sélectionné en EEPROM (survit aux coupures de courant)
- LED témoin et buzzer de fin de cycle
- Mode de test des vannes : actionne chaque vanne individuellement pour vérifier le câblage
- Arrêt d'urgence via contacteur (bouton coup-de-poing)

---

## Matériel

| Composant | Détails |
|---|---|
| Contrôleur | Arduino Uno (ATmega328P) |
| Carte de relais | 16 canaux, logique active-low, 12 V |
| Électrovannes | 9 × 12 V |
| Pompe | Novax 20B (ou équivalent) |
| Résistance chauffante | 2500 W (thermoplongeur) |
| Thermostat | STC1000 |
| SSR | 40 A + radiateur + ventilateur 12 V |
| Afficheur | LCD I²C 16×2 |
| Interface | Encodeur rotatif (A1/A2) + bouton action (A3) |

---

## Tester dans le navigateur

Une simulation Wokwi complète est disponible — sans matériel :

**[▶ Ouvrir la simulation](https://wokwi.com/projects/464738080652364801)**

Les électrovannes sont représentées par des LEDs avec leurs labels. Le sketch complet fonctionne sans modification. Note : Wokwi simule le temps plus lentement que la réalité.

---

## Structure du dépôt

```
/
├── kegwasher.ino               — Firmware Arduino (branche main)
├── CHANGELOG.md                — Historique des forks et des modifications
├── CONTRIBUTING.md             — Comment contribuer
├── LICENSE                     — GNU GPL v3
│
├── docs/
│   ├── EN/
│   │   ├── USER_MANUAL.md      — Manuel d'utilisation (EN)
│   │   ├── README_TECHNICAL.md — Choix techniques du firmware
│   │   ├── ELECTRONICS_HOWTO.md— Guide de câblage et d'assemblage
│   │   ├── MAINTENANCE_GUIDE.md— Entretien
│   │   └── GRAFCET_ALL_MODES.md— Diagrammes de séquences (tous modes)
│   └── FR/
│       ├── README_FR.md
│       ├── MANUEL_UTILISATION.md
│       ├── README_TECHNIQUE.md
│       ├── GUIDE_ELECTRONIQUE.md
│       ├── GUIDE_ENTRETIEN.md
│       └── GRAFCET_TOUS_MODES.md
│
├── fritzing/
│   ├── kegwasher.fzz           — Source Fritzing
│   └── kegwasher.png           — Schéma de câblage
│
└── Images/                     — Photos et illustrations
```

---

## Documentation

| Document | EN | FR |
|---|---|---|
| Manuel d'utilisation | [EN](../EN/USER_MANUAL.md) | [FR](MANUEL_UTILISATION.md) |
| README technique | [EN](../EN/README_TECHNICAL.md) | [FR](README_TECHNIQUE.md) |
| Guide d'assemblage électronique | [EN](../EN/ELECTRONICS_HOWTO.md) | [FR](GUIDE_ELECTRONIQUE.md) |
| Guide d'entretien | [EN](../EN/MAINTENANCE_GUIDE.md) | [FR](GUIDE_ENTRETIEN.md) |
| Diagrammes de séquences | [EN](../EN/GRAFCET_ALL_MODES.md) | [FR](GRAFCET_TOUS_MODES.md) |

---

## Historique des forks

| Génération | Auteur | Contributions |
|---|---|---|
| v1 | [vieuxsinge](https://github.com/vieuxsinge/kegwasher) | Projet original : moteur de séquences, modèle bitmask, programmes de lavage, machine à états |
| v2 | [Gummy35](https://github.com/Gummy35/kegwasher) | Séquencement ordonné des actionneurs, affichage LCD alterné, nouveaux modes, pressurisation CO₂ |
| v3 | [ecolab07](https://github.com/ecolab07/kegwasher) | Mode test vannes, transitions minimales, corrections de timing, typage, améliorations hardware |

Voir [CHANGELOG.md](../../CHANGELOG.md) pour l'historique détaillé complet.

---

## Contribuer

Voir [CONTRIBUTING.md](../../CONTRIBUTING.md). Issues et pull requests bienvenus.

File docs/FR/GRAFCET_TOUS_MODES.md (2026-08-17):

# GRAFCET des modes — Keg Washer

Un diagramme par mode. Colonne de gauche « Actionneurs utilisés » (sans bordure, en miroir vertical) + colonne de droite « Étapes » (boîtes normales). Les cycles identiques répétés sont regroupés dans un sous-graphe (ex. « Cycle détergent ») plutôt que dupliqués visuellement en boucle.

Référence firmware : `MODES[]` dans `kegwasher.ino`.

> Pour la description de chaque mode (cas d'usage, quand l'utiliser), voir le [Manuel d'utilisation](MANUEL_UTILISATION.md).

## Sommaire

1. [Lavage + CO2](#1--lavage--co2)
2. [Lavage sans CO2](#2--lavage-sans-co2)
3. [Détergent seul](#3--détergent-seul)
4. [CO2](#4--co2)
5. [Désinfection + CO2](#5--désinfection--co2)
6. [Vidange fût](#6--vidange-fût)
7. [Vidange désinfectant](#7--vidange-désinfectant)
8. [Vidange détergent](#8--vidange-détergent)
9. [Remplissage désinfectant](#9--remplissage-désinfectant)
10. [Remplissage détergent](#10--remplissage-détergent)
11. [Test vannes](#11--test-vannes)

---

## 1 — Lavage + CO2

Source : `STEPS_WASH_KEG_PRESSURIZE` — ≈ 5 min 30

```mermaid
flowchart TD
    subgraph ACTUATORS["Actionneurs utilisés"]
    direction TD
        A(["Actionneurs<br/>au repos"])
        B("EGOUT")
        C("POMPE&nbsp;+&nbsp;EAU&nbsp;+&nbsp;EGOUT<br/>AIR&nbsp;+&nbsp;EGOUT")
        D("POMPE&nbsp;+&nbsp;EAU&nbsp;+&nbsp;EGOUT<br/>CO2&nbsp;+&nbsp;EGOUT<br/>CO2")
        E(["Actionneurs<br/>au repos"])
        subgraph CL["&nbsp;"]
            direction TB
            CL1("POMPE&nbsp;+&nbsp;DETERG_IN&nbsp;+&nbsp;DETERG_OUT<br/>AIR&nbsp;+&nbsp;DETERG_OUT")
            CL2("POMPE&nbsp;+&nbsp;DETERG_IN&nbsp;+&nbsp;DETERG_OUT<br/>AIR&nbsp;+&nbsp;DETERG_OUT")
            CL3("POMPE&nbsp;+&nbsp;DETERG_IN&nbsp;+&nbsp;DETERG_OUT<br/>AIR&nbsp;+&nbsp;DETERG_OUT")
            CL1 ~~~ CL2 ~~~ CL3
        end
        subgraph RI["&nbsp;"]
            direction TB
            RI1("POMPE&nbsp;+&nbsp;EAU&nbsp;+&nbsp;EGOUT<br/>AIR&nbsp;+&nbsp;EGOUT")
            RI2("POMPE&nbsp;+&nbsp;EAU&nbsp;+&nbsp;EGOUT<br/>AIR&nbsp;+&nbsp;EGOUT")
            RI3("POMPE&nbsp;+&nbsp;EAU&nbsp;+&nbsp;EGOUT<br/>AIR&nbsp;+&nbsp;EGOUT")
            RI1 ~~~ RI2 ~~~ RI3
        end
        subgraph SA["&nbsp;"]
            direction TB
            SA1("POMPE&nbsp;+&nbsp;DESINF_IN&nbsp;+&nbsp;DESINF_OUT<br/>AIR&nbsp;+&nbsp;DESINF_OUT")
            SA2("POMPE&nbsp;+&nbsp;DESINF_IN&nbsp;+&nbsp;DESINF_OUT<br/>AIR&nbsp;+&nbsp;DESINF_OUT")
            SA3("POMPE&nbsp;+&nbsp;DESINF_IN&nbsp;+&nbsp;DESINF_OUT<br/>AIR&nbsp;+&nbsp;DESINF_OUT")
            SA1 ~~~ SA2 ~~~ SA3
        end
        A ~~~ |&nbsp;| B ~~~ C
        C ~~~ CL1
        CL3 ~~~ RI1
        RI3 ~~~ SA1
        SA3 ~~~ D
        D ~~~ E
    end
    style ACTUATORS fill:none,stroke:none
    style CL fill:none,stroke:none
    style RI fill:none,stroke:none
    style SA fill:none,stroke:none
    style B fill:none,stroke:none
    style C fill:none,stroke:none
    style D fill:none,stroke:none
    style CL1 fill:none,stroke:none
    style CL2 fill:none,stroke:none
    style CL3 fill:none,stroke:none
    style RI1 fill:none,stroke:none
    style RI2 fill:none,stroke:none
    style RI3 fill:none,stroke:none
    style SA1 fill:none,stroke:none
    style SA2 fill:none,stroke:none
    style SA3 fill:none,stroke:none
    subgraph STEPS["Mode Lavage + CO2"]
        direction TB
        Start(["Sélection du mode<br/>Lavage + CO₂"])
        Drain["Vidange 10 s"]
        Rinse0["Rinçage initial 10 s<br/>Purge 20 s"]
        subgraph CLEAN["Cycle détergent"]
            direction TB
            C1["Détergent 10 s<br/>Purge 15 s"]
            C2["Détergent 10 s<br/>Purge 15 s"]
            C3["Détergent 10 s<br/>Purge 20 s"]
            C1 --> C2 --> C3
        end
        subgraph RINSE["Rinçage intermédiaire"]
            direction TB
            R1["Rinçage 3 s<br/>Purge 10 s"]
            R2["Rinçage 7 s<br/>Purge 10 s"]
            R3["Rinçage 10 s<br/>Purge 20 s"]
            R1 --> R2 --> R3
        end
        subgraph SAN["Cycle désinfection"]
            direction TB
            S1["Désinfectant 10 s<br/>Purge 15 s"]
            S2["Désinfectant 10 s<br/>Purge 15 s"]
            S3["Désinfectant 30 s<br/>Purge 20 s"]
            S1 --> S2 --> S3
        end
        Final["Rinçage final 10 s<br/>Purge CO2 30 s<br/>Pressurisation CO2 10 s"]
        End(["Fin de cycle<br/>3 bips"])
        Start -->|Appui bouton| Drain
        Drain --> Rinse0
        Rinse0 --> C1
        C3 --> R1
        R3 --> S1
        S3 --> Final
        Final --> End
    end
```

---

## 2 — Lavage sans CO2

Source : `STEPS_WASH_KEG` — ≈ 5 min 20

```mermaid
flowchart TD
    subgraph ACTUATORS["Actionneurs utilisés"]
    direction TD
        A(["Actionneurs<br/>au repos"])
        B("EGOUT")
        C("POMPE&nbsp;+&nbsp;EAU&nbsp;+&nbsp;EGOUT<br/>AIR&nbsp;+&nbsp;EGOUT")
        D("POMPE&nbsp;+&nbsp;EAU&nbsp;+&nbsp;EGOUT<br/>AIR&nbsp;+&nbsp;EGOUT")
        E(["Actionneurs<br/>au repos"])
        subgraph CL["&nbsp;"]
            direction TB
            CL1("POMPE&nbsp;+&nbsp;DETERG_IN&nbsp;+&nbsp;DETERG_OUT<br/>AIR&nbsp;+&nbsp;DETERG_OUT")
            CL2("POMPE&nbsp;+&nbsp;DETERG_IN&nbsp;+&nbsp;DETERG_OUT<br/>AIR&nbsp;+&nbsp;DETERG_OUT")
            CL3("POMPE&nbsp;+&nbsp;DETERG_IN&nbsp;+&nbsp;DETERG_OUT<br/>AIR&nbsp;+&nbsp;DETERG_OUT")
            CL1 ~~~ CL2 ~~~ CL3
        end
        subgraph RI["&nbsp;"]
            direction TB
            RI1("POMPE&nbsp;+&nbsp;EAU&nbsp;+&nbsp;EGOUT<br/>AIR&nbsp;+&nbsp;EGOUT")
            RI2("POMPE&nbsp;+&nbsp;EAU&nbsp;+&nbsp;EGOUT<br/>AIR&nbsp;+&nbsp;EGOUT")
            RI3("POMPE&nbsp;+&nbsp;EAU&nbsp;+&nbsp;EGOUT<br/>AIR&nbsp;+&nbsp;EGOUT")
            RI1 ~~~ RI2 ~~~ RI3
        end
        subgraph SA["&nbsp;"]
            direction TB
            SA1("POMPE&nbsp;+&nbsp;DESINF_IN&nbsp;+&nbsp;DESINF_OUT<br/>AIR&nbsp;+&nbsp;DESINF_OUT")
            SA2("POMPE&nbsp;+&nbsp;DESINF_IN&nbsp;+&nbsp;DESINF_OUT<br/>AIR&nbsp;+&nbsp;DESINF_OUT")
            SA3("POMPE&nbsp;+&nbsp;DESINF_IN&nbsp;+&nbsp;DESINF_OUT<br/>AIR&nbsp;+&nbsp;DESINF_OUT")
            SA1 ~~~ SA2 ~~~ SA3
        end
        A ~~~ |&nbsp;| B ~~~ C
        C ~~~ CL1
        CL3 ~~~ RI1
        RI3 ~~~ SA1
        SA3 ~~~ D
        D ~~~ E
    end
    style ACTUATORS fill:none,stroke:none
    style CL fill:none,stroke:none
    style RI fill:none,stroke:none
    style SA fill:none,stroke:none
    style B fill:none,stroke:none
    style C fill:none,stroke:none
    style D fill:none,stroke:none
    style CL1 fill:none,stroke:none
    style CL2 fill:none,stroke:none
    style CL3 fill:none,stroke:none
    style RI1 fill:none,stroke:none
    style RI2 fill:none,stroke:none
    style RI3 fill:none,stroke:none
    style SA1 fill:none,stroke:none
    style SA2 fill:none,stroke:none
    style SA3 fill:none,stroke:none
    subgraph STEPS["Mode Lavage sans CO2"]
        direction TB
        Start(["Sélection du mode<br/>Lavage sans CO₂"])
        Drain["Vidange 10 s"]
        Rinse0["Rinçage initial 10 s<br/>Purge 20 s"]
        subgraph CLEAN["Cycle détergent"]
            direction TB
            C1["Détergent 10 s<br/>Purge 15 s"]
            C2["Détergent 10 s<br/>Purge 15 s"]
            C3["Détergent 10 s<br/>Purge 20 s"]
            C1 --> C2 --> C3
        end
        subgraph RINSE["Rinçage intermédiaire"]
            direction TB
            R1["Rinçage 3 s<br/>Purge 10 s"]
            R2["Rinçage 7 s<br/>Purge 10 s"]
            R3["Rinçage 10 s<br/>Purge 20 s"]
            R1 --> R2 --> R3
        end
        subgraph SAN["Cycle désinfection"]
            direction TB
            S1["Désinfectant 10 s<br/>Purge 15 s"]
            S2["Désinfectant 10 s<br/>Purge 15 s"]
            S3["Désinfectant 30 s<br/>Purge 20 s"]
            S1 --> S2 --> S3
        end
        Final["Rinçage final 10 s<br/>Purge 30 s"]
        End(["Fin de cycle<br/>3 bips"])
        Start -->|Appui bouton| Drain
        Drain --> Rinse0
        Rinse0 --> C1
        C3 --> R1
        R3 --> S1
        S3 --> Final
        Final --> End
    end
```

---

## 3 — Détergent seul

Source : `STEPS_DETER_KEG` — ≈ 3 min 00. Pas de cycle désinfection, pas de rinçage final séparé : le cycle de rinçage intermédiaire termine directement le mode.

```mermaid
flowchart TD
    subgraph ACTUATORS["Actionneurs utilisés"]
    direction TD
        A(["Actionneurs<br/>au repos"])
        B("EGOUT")
        C("POMPE&nbsp;+&nbsp;EAU&nbsp;+&nbsp;EGOUT<br/>AIR&nbsp;+&nbsp;EGOUT")
        E(["Actionneurs<br/>au repos"])
        subgraph CL["&nbsp;"]
            direction TB
            CL1("POMPE&nbsp;+&nbsp;DETERG_IN&nbsp;+&nbsp;DETERG_OUT<br/>AIR&nbsp;+&nbsp;DETERG_OUT")
            CL2("POMPE&nbsp;+&nbsp;DETERG_IN&nbsp;+&nbsp;DETERG_OUT<br/>AIR&nbsp;+&nbsp;DETERG_OUT")
            CL3("POMPE&nbsp;+&nbsp;DETERG_IN&nbsp;+&nbsp;DETERG_OUT<br/>AIR&nbsp;+&nbsp;DETERG_OUT")
            CL1 ~~~ CL2 ~~~ CL3
        end
        subgraph RI["&nbsp;"]
            direction TB
            RI1("POMPE&nbsp;+&nbsp;EAU&nbsp;+&nbsp;EGOUT<br/>AIR&nbsp;+&nbsp;EGOUT")
            RI2("POMPE&nbsp;+&nbsp;EAU&nbsp;+&nbsp;EGOUT<br/>AIR&nbsp;+&nbsp;EGOUT")
            RI3("POMPE&nbsp;+&nbsp;EAU&nbsp;+&nbsp;EGOUT<br/>AIR&nbsp;+&nbsp;EGOUT")
            RI1 ~~~ RI2 ~~~ RI3
        end
        A ~~~ |&nbsp;| B ~~~ C
        C ~~~ CL1
        CL3 ~~~ RI1
        RI3 ~~~ E
    end
    style ACTUATORS fill:none,stroke:none
    style CL fill:none,stroke:none
    style RI fill:none,stroke:none
    style B fill:none,stroke:none
    style C fill:none,stroke:none
    style CL1 fill:none,stroke:none
    style CL2 fill:none,stroke:none
    style CL3 fill:none,stroke:none
    style RI1 fill:none,stroke:none
    style RI2 fill:none,stroke:none
    style RI3 fill:none,stroke:none
    subgraph STEPS["Mode Détergent seul"]
        direction TB
        Start(["Sélection du mode<br/>Détergent seul"])
        Drain["Vidange 10 s"]
        Rinse0["Rinçage initial 10 s<br/>Purge 20 s"]
        subgraph CLEAN["Cycle détergent"]
            direction TB
            C1["Détergent 10 s<br/>Purge 15 s"]
            C2["Détergent 10 s<br/>Purge 15 s"]
            C3["Détergent 10 s<br/>Purge 20 s"]
            C1 --> C2 --> C3
        end
        subgraph RINSE["Rinçage intermédiaire"]
            direction TB
            R1["Rinçage 3 s<br/>Purge 10 s"]
            R2["Rinçage 7 s<br/>Purge 10 s"]
            R3["Rinçage 10 s<br/>Purge 20 s"]
            R1 --> R2 --> R3
        end
        End(["Fin de cycle<br/>3 bips"])
        Start -->|Appui bouton| Drain
        Drain --> Rinse0
        Rinse0 --> C1
        C3 --> R1
        R3 --> End
    end
```

---

## 4 — CO2

Source : `STEPS_KEG_PRESSURIZE` — 50 s. Mode le plus court, purement linéaire.

```mermaid
flowchart TD
    subgraph ACTUATORS["Actionneurs utilisés"]
    direction TD
        A(["Actionneurs<br/>au repos"])
        B("EGOUT")
        C("CO2&nbsp;+&nbsp;EGOUT")
        D("CO2")
        E(["Actionneurs<br/>au repos"])
        A ~~~ |&nbsp;| B ~~~ C ~~~ D ~~~ E
    end
    style ACTUATORS fill:none,stroke:none
    style B fill:none,stroke:none
    style C fill:none,stroke:none
    style D fill:none,stroke:none
    subgraph STEPS["Mode CO2"]
        direction TB
        Start(["Sélection du mode<br/>CO2"])
        Drain["Vidange 10 s"]
        Purge["Purge CO2 30 s"]
        Press["Pressurisation CO2 10 s"]
        End(["Fin de cycle<br/>3 bips"])
        Start -->|Appui bouton| Drain
        Drain --> Purge
        Purge --> Press
        Press --> End
    end
```

---

## 5 — Désinfection + CO2

Source : `STEPS_SANITIZE_KEG_PRESSURIZE` — ≈ 3 min 10

```mermaid
flowchart TD
    subgraph ACTUATORS["Actionneurs utilisés"]
    direction TD
        A(["Actionneurs<br/>au repos"])
        B("EGOUT")
        C("POMPE&nbsp;+&nbsp;EAU&nbsp;+&nbsp;EGOUT<br/>AIR&nbsp;+&nbsp;EGOUT")
        D("POMPE&nbsp;+&nbsp;EAU&nbsp;+&nbsp;EGOUT<br/>CO2&nbsp;+&nbsp;EGOUT<br/>CO2")
        E(["Actionneurs<br/>au repos"])
        subgraph SA["&nbsp;"]
            direction TB
            SA1("POMPE&nbsp;+&nbsp;DESINF_IN&nbsp;+&nbsp;DESINF_OUT<br/>AIR&nbsp;+&nbsp;DESINF_OUT")
            SA2("POMPE&nbsp;+&nbsp;DESINF_IN&nbsp;+&nbsp;DESINF_OUT<br/>AIR&nbsp;+&nbsp;DESINF_OUT")
            SA3("POMPE&nbsp;+&nbsp;DESINF_IN&nbsp;+&nbsp;DESINF_OUT<br/>AIR&nbsp;+&nbsp;DESINF_OUT")
            SA1 ~~~ SA2 ~~~ SA3
        end
        A ~~~ |&nbsp;| B ~~~ C
        C ~~~ SA1
        SA3 ~~~ D
        D ~~~ E
    end
    style ACTUATORS fill:none,stroke:none
    style SA fill:none,stroke:none
    style B fill:none,stroke:none
    style C fill:none,stroke:none
    style D fill:none,stroke:none
    style SA1 fill:none,stroke:none
    style SA2 fill:none,stroke:none
    style SA3 fill:none,stroke:none
    subgraph STEPS["Mode Désinfection + CO2"]
        direction TB
        Start(["Sélection du mode<br/>Désinf. + CO₂"])
        Drain["Vidange 10 s"]
        Rinse0["Rinçage initial 10 s<br/>Purge 20 s"]
        subgraph SAN["Cycle désinfection"]
            direction TB
            S1["Désinfectant 10 s<br/>Purge 15 s"]
            S2["Désinfectant 10 s<br/>Purge 15 s"]
            S3["Désinfectant 30 s<br/>Purge 20 s"]
            S1 --> S2 --> S3
        end
        Final["Rinçage final 10 s<br/>Purge CO2 30 s<br/>Pressurisation CO2 10 s"]
        End(["Fin de cycle<br/>3 bips"])
        Start -->|Appui bouton| Drain
        Drain --> Rinse0
        Rinse0 --> S1
        S3 --> Final
        Final --> End
    end
```

---

## 6 — Vidange fût

Source : `STEPS_DRAIN_KEG` — 70 s

```mermaid
flowchart TD
    subgraph ACTUATORS["Actionneurs utilisés"]
    direction TD
        A(["Actionneurs<br/>au repos"])
        B("EGOUT")
        C("AIR&nbsp;+&nbsp;EGOUT")
        E(["Actionneurs<br/>au repos"])
        A ~~~ |&nbsp;| B ~~~ C ~~~ E
    end
    style ACTUATORS fill:none,stroke:none
    style B fill:none,stroke:none
    style C fill:none,stroke:none
    subgraph STEPS["Mode Vidange fût"]
        direction TB
        Start(["Sélection du mode<br/>Vidange fût"])
        Drain["Vidange 10 s"]
        Purge["Purge air 60 s"]
        End(["Fin de cycle<br/>3 bips"])
        Start -->|Appui bouton| Drain
        Drain --> Purge
        Purge --> End
    end
```

---

## 7 — Vidange désinfectant

Source : `STEPS_DRAIN_SANITIZER` — 200 s, une seule étape.

```mermaid
flowchart TD
    subgraph ACTUATORS["Actionneurs utilisés"]
    direction TD
        A(["Actionneurs<br/>au repos"])
        B("POMPE&nbsp;+&nbsp;DESINF_IN&nbsp;+&nbsp;EGOUT")
        E(["Actionneurs<br/>au repos"])
        A ~~~ |&nbsp;| B ~~~ E
    end
    style ACTUATORS fill:none,stroke:none
    style B fill:none,stroke:none
    subgraph STEPS["Mode Vidange désinfectant"]
        direction TB
        Start(["Sélection du mode<br/>Vidange désinf."])
        Drain["Vidange cuve désinfectant<br/>200 s"]
        End(["Fin de cycle<br/>3 bips"])
        Start -->|Appui bouton| Drain
        Drain --> End
    end
```

---

## 8 — Vidange détergent

Source : `STEPS_DRAIN_CLEANER` — 200 s, une seule étape.

```mermaid
flowchart TD
    subgraph ACTUATORS["Actionneurs utilisés"]
    direction TD
        A(["Actionneurs<br/>au repos"])
        B("POMPE&nbsp;+&nbsp;DETERG_IN&nbsp;+&nbsp;EGOUT")
        E(["Actionneurs<br/>au repos"])
        A ~~~ |&nbsp;| B ~~~ E
    end
    style ACTUATORS fill:none,stroke:none
    style B fill:none,stroke:none
    subgraph STEPS["Mode Vidange détergent"]
        direction TB
        Start(["Sélection du mode<br/>Vidange déter."])
        Drain["Vidange cuve détergent<br/>200 s"]
        End(["Fin de cycle<br/>3 bips"])
        Start -->|Appui bouton| Drain
        Drain --> End
    end
```

---

## 9 — Remplissage désinfectant

Source : `STEPS_FILL_SANITIZER` — 120 s, une seule étape.

```mermaid
flowchart TD
    subgraph ACTUATORS["Actionneurs utilisés"]
    direction TD
        A(["Actionneurs<br/>au repos"])
        B("POMPE&nbsp;+&nbsp;DESINF_OUT&nbsp;+&nbsp;EAU")
        E(["Actionneurs<br/>au repos"])
        A ~~~ |&nbsp;| B ~~~ E
    end
    style ACTUATORS fill:none,stroke:none
    style B fill:none,stroke:none
    subgraph STEPS["Mode Remplissage désinfectant"]
        direction TB
        Start(["Sélection du mode<br/>Rempl. désinf."])
        Fill["Remplissage&nbsp;cuve&nbsp;désinfectant<br/>120 s"]
        End(["Fin de cycle<br/>3 bips"])
        Start -->|Appui bouton| Fill
        Fill --> End
    end
```

---

## 10 — Remplissage détergent

Source : `STEPS_FILL_CLEANER` — 120 s, une seule étape.

```mermaid
flowchart TD
    subgraph ACTUATORS["Actionneurs utilisés"]
    direction TD
        A(["Actionneurs<br/>au repos"])
        B("POMPE&nbsp;+&nbsp;DETERG_OUT&nbsp;+&nbsp;EAU")
        E(["Actionneurs<br/>au repos"])
        A ~~~ |&nbsp;| B ~~~ E
    end
    style ACTUATORS fill:none,stroke:none
    style B fill:none,stroke:none
    subgraph STEPS["Mode Remplissage détergent"]
        direction TB
        Start(["Sélection du mode<br/>Rempl. déter."])
        Fill["Remplissage&nbsp;cuve&nbsp;détergent<br/>120 s"]
        End(["Fin de cycle<br/>3 bips"])
        Start -->|Appui bouton| Fill
        Fill --> End
    end
```

---

## 11 — Test vannes

Source : `STEPS_TEST_ACTUATORS` — 24 s.

**Écart au gabarit :** ce mode ne suit pas le schéma à deux colonnes. Chaque étape active un actionneur *différent* (pas de bloc identique répété), donc la colonne « Actionneurs » serait redondante avec le nom de l'étape elle-même. Diagramme à une seule colonne, purement séquentiel.

```mermaid
flowchart TD
    subgraph STEPS["Mode Test vannes"]
        direction TB
        Start(["Sélection du mode<br/>Test vannes"])
        Warn{{"Confirmation :<br/>cuves vides ?<br/>5 s"}}
        T1["Vanne retour désinfectant<br/>1 s"]
        T2["Vanne vidange<br/>1 s"]
        T3["Vanne retour détergent<br/>1 s"]
        T4["Vanne air<br/>1 s"]
        T5["Vanne CO2<br/>1 s"]
        T6["Vanne entrée désinfectant<br/>1 s"]
        T7["Vanne eau<br/>1 s"]
        T8["Vanne entrée détergent<br/>1 s"]
        T9["Pompe<br/>1 s"]
        End(["Fin de cycle<br/>3 bips"])
        Start -->|Appui bouton| Warn
        Warn -->|attente 1 s| T1
        T1 -->|attente 1 s| T2
        T2 -->|attente 1 s| T3
        T3 -->|attente 1 s| T4
        T4 -->|attente 1 s| T5
        T5 -->|attente 1 s| T6
        T6 -->|attente 1 s| T7
        T7 -->|attente 1 s| T8
        T8 -->|attente 1 s| T9
        T9 --> End
    end
```

**Note valable pour les 11 modes :** un appui sur le bouton pendant l'exécution annule la séquence en cours (fermeture des vannes, 1 bip, retour à l'écran de sélection) — non représenté sur chaque diagramme pour ne pas les surcharger.

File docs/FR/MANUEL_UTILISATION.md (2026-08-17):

# Manuel d'utilisation — Laveuse de fûts automatique

> Ce projet est un fork de [vieuxsinge/kegwasher](https://github.com/vieuxsinge/kegwasher)
> et de [Gummy35/kegwasher](https://github.com/Gummy35/kegwasher).
> Licence : GNU GPL v3.

---

## Table des matières

1. [Présentation générale](#1-présentation-générale)
2. [Prérequis avant utilisation](#2-prérequis-avant-utilisation)
3. [Interface utilisateur](#3-interface-utilisateur)
4. [Démarrage et sélection d'un mode](#4-démarrage-et-sélection-dun-mode)
5. [Description des modes](#5-description-des-modes)
6. [Pendant le lavage](#6-pendant-le-lavage)
7. [Fin de cycle](#7-fin-de-cycle)
8. [Annulation d'un cycle](#8-annulation-dun-cycle)
9. [Arrêt d'urgence](#9-arrêt-durgence)
10. [Après utilisation](#10-après-utilisation)
11. [Conseils pratiques](#11-conseils-pratiques)

---

## 1. Présentation générale

La laveuse de fûts automatique permet de nettoyer des fûts en inox **sans démonter les plongeurs**. Les produits de nettoyage sont injectés via des têtes de lavage et circulent à l'intérieur du fût grâce à une pompe.

La machine peut laver **2 fûts simultanément**.

Elle dispose de :
- 2 cuves produits : **détergent** (soude à 2 %, maintenue à 80 °C) et **désinfectant** (acide peracétique à 1 %)
- 1 arrivée d'eau du réseau
- 1 arrivée d'air comprimé
- 1 arrivée de CO₂
- 1 évacuation vers le caniveau

Un cycle de lavage complet dure environ **5 minutes 30 secondes**.

---

## 2. Prérequis avant utilisation

Avant de lancer tout cycle, vérifier les points suivants :

- [ ] Les **cuves produits sont à niveau** (détergent et désinfectant)
- [ ] La **cuve de détergent est à température** (80 °C, vérifier le thermostat STC1000)
- [ ] L'**arrivée d'eau** est ouverte
- [ ] L'**arrivée d'air comprimé** est ouverte (pression recommandée : **2,5 bar**)
- [ ] L'**arrivée de CO₂** est ouverte (pression recommandée : **2,5 bar**)
- [ ] Les **fûts sont connectés** aux têtes de lavage (plongeur vers le bas)
- [ ] L'**évacuation** est dégagée
- [ ] Le **bouton d'arrêt d'urgence** est déverrouillé (tourner pour libérer)

---

## 3. Interface utilisateur

La machine dispose de trois éléments de contrôle sur la façade :

| Élément | Rôle |
|---|---|
| **Encodeur rotatif** | Navigation dans le menu (tourner = changer de mode) |
| **Bouton action** | Valider le mode sélectionné / annuler un cycle en cours |
| **Bouton d'arrêt d'urgence** | Coupure générale immédiate de l'alimentation |

L'**écran LCD** (2 lignes × 16 caractères) affiche :
- Ligne 1 : le nom du mode sélectionné ou l'étape en cours
- Ligne 2 : la progression du cycle (temps écoulé / temps total)

La **LED** sur la façade :
- **Allumée fixe** : en attente de sélection
- **Clignotante** : cycle en cours

Le **buzzer** émet :
- **1 bip** : cycle annulé
- **3 bips** : cycle terminé normalement

---

## 4. Démarrage et sélection d'un mode

1. Mettre la machine sous tension.
2. L'écran affiche `Mode :` sur la première ligne et le nom du dernier mode utilisé sur la seconde *(le dernier mode est mémorisé en cas de coupure de courant)*.
3. **Tourner l'encodeur** pour naviguer dans la liste des modes.
4. **Appuyer sur le bouton action** pour lancer le mode affiché.
5. L'écran affiche `Preparation` le temps que la machine configure les électrovannes, puis le cycle démarre.

---

## 5. Description des modes

> Pour les diagrammes de séquences de chaque mode (quels actionneurs sont actifs à chaque étape), voir les [Diagrammes de séquences (GRAFCET)](GRAFCET_TOUS_MODES.md).

### Modes de lavage complets

#### `Lavage + CO2` — 330 s (5 min 30)
Mode de lavage complet recommandé pour un fût ayant contenu de la bière.

| Phase | Durée | Description |
|---|---|---|
| Vidange initiale | 10 s | Évacuation du contenu résiduel vers le caniveau |
| Rinçage initial | 30 s | Passage d'eau + purge air, chasse les résidus grossiers |
| Détergent (×3) | 75 s | Circulation de soude chaude à 80 °C + purge air entre chaque passe |
| Rinçage intermédiaire (×3) | 60 s | Élimination complète des traces de détergent |
| Désinfectant (×3) | 65 s | Circulation d'acide peracétique + purge air entre chaque passe |
| Rinçage final + purge CO₂ | 40 s | Eau + purge CO₂ pour chasser l'oxygène |
| Mise sous pression CO₂ | 10 s | Pressurisation du fût avant remplissage |

✅ **Fût prêt à être rempli directement.**

---

#### `Lavage sans CO2` — 320 s (5 min 20)
Identique au mode précédent mais sans l'étape de pressurisation finale au CO₂. La purge finale est à l'air comprimé.

À utiliser si la mise sous pression CO₂ est faite séparément, ou si le fût n'est pas rempli immédiatement.

---

#### `Detergent seul` — 180 s (3 min 00)
Lavage au détergent et rinçages uniquement, sans étape de désinfection ni CO₂.

À utiliser pour un nettoyage rapide entre deux utilisations rapprochées, ou quand la désinfection sera faite dans un second temps.

---

### Modes de désinfection et pressurisation

#### `Desinf. + CO2` — 190 s (3 min 10)
Désinfection seule suivie d'une purge CO₂ et d'une pressurisation.

À utiliser sur un fût **déjà nettoyé au détergent** dans une session précédente.

---

#### `CO2` — 50 s
Purge CO₂ + pressurisation uniquement, sans produit chimique.

À utiliser pour re-pressuriser un fût propre qui a été laissé ouvert, ou pour chasser l'air résiduel.

---

### Modes de maintenance des cuves produits

#### `Vidange fut` — 70 s (1 min 10)
Vidange du fût via le caniveau, suivie d'une longue purge à l'air pour sécher les lignes.

À utiliser pour vider un fût avant de le stocker ou de le renvoyer.

---

#### `Vidange desinf.` — 200 s (3 min 20)
Vidange de la **cuve désinfectant** à travers le circuit vers le caniveau via la pompe.

À utiliser en fin de session pour vider la cuve de désinfectant, ou pour renouveler la solution.

---

#### `Vidange deter.` — 200 s (3 min 20)
Vidange de la **cuve détergent** à travers le circuit vers le caniveau via la pompe.

À utiliser pour renouveler la solution de détergent ou en fin de saison.

---

#### `Rempl. desinf.` — 120 s (2 min 00)
Remplissage de la **cuve désinfectant** avec de l'eau du réseau. L'eau entre dans le fût via l'arrivée d'eau, puis est pompée vers la cuve désinfectant via la vanne de retour (`SANITIZER_OUT`).

> ⚠️ S'assurer que la cuve est vide ou à un niveau permettant d'accueillir le volume d'eau avant de lancer ce mode.

---

#### `Rempl. deter.` — 120 s (2 min 00)
Remplissage de la **cuve détergent** avec de l'eau du réseau. L'eau entre dans le fût via l'arrivée d'eau, puis est pompée vers la cuve détergent via la vanne de retour (`CLEANER_OUT`).

> ⚠️ Même précaution que pour le remplissage désinfectant. Penser à ajouter la soude après le remplissage.

---

### Mode de test

#### `Test vannes` — 24 s
Active chaque actionneur **individuellement** pendant 1 seconde, dans l'ordre physique des relais (de gauche à droite et de haut en bas sur la carte).

> ⚠️ **Les cuves doivent être vides avant de lancer ce mode.** L'écran affiche `Cuves vides ?` pendant 5 secondes au démarrage. Attendre ce message et vérifier avant que le test ne commence.

À utiliser pour vérifier le câblage, diagnostiquer une électrovanne silencieuse ou confirmer que la machine est correctement assemblée.

Ordre de déclenchement : désinfectant retour → caniveau → détergent retour → air → CO₂ → désinfectant entrée → eau → détergent entrée → pompe.

---

## 6. Pendant le lavage

- L'écran affiche en ligne 1 le nom de l'étape en cours (alterne avec le nom du mode).
- L'écran affiche en ligne 2 le temps écoulé et le temps total du cycle.
- La LED clignote toutes les 2 secondes.
- **Ne pas débrancher les fûts pendant le cycle.**

---

## 7. Fin de cycle

Lorsque toutes les étapes sont terminées :
1. Toutes les électrovannes se ferment et la pompe s'arrête.
2. La LED s'éteint.
3. L'écran affiche `Termine`.
4. Le buzzer émet **3 bips**.
5. La machine revient automatiquement au menu de sélection.

---

## 8. Annulation d'un cycle

Appuyer sur le **bouton action** pendant un cycle en cours pour l'annuler immédiatement :
1. Toutes les électrovannes se ferment et la pompe s'arrête.
2. L'écran affiche `Annule`.
3. Le buzzer émet **1 bip**.
4. La machine revient au menu de sélection.

> ⚠️ En cas d'annulation en cours de cycle, les fûts et les lignes peuvent contenir des résidus de produit. Relancer un cycle de rinçage avant de remplir les fûts.

---

## 9. Arrêt d'urgence

Le bouton **coup-de-poing** sur la façade coupe l'alimentation générale via un contacteur.

Il agit sur **toute la machine** (pompe, électrovannes, Arduino).

Pour réarmer : **tourner le bouton** dans le sens indiqué jusqu'au déclic.

> ⚠️ Après un arrêt d'urgence, toutes les électrovannes se trouvent dans leur état de repos (fermé = sécurité). Vérifier l'état du circuit avant de remettre sous tension.

---

## 10. Après utilisation

- Vérifier que les cuves produits sont à niveau pour la prochaine session.
- Si la session est terminée pour la journée, laisser les cuves produits en place (elles sont conçues pour rester en circuit).
- Fermer les arrivées d'eau, d'air et de CO₂ si la machine n'est pas utilisée pendant une longue période.
- Rincer et sécher les têtes de lavage.

---

## 11. Conseils pratiques

- **Optimisation du temps** : le lavage (5 min) peut être réalisé en parallèle du remplissage des fûts déjà propres. C'est tout l'intérêt de l'automatisation.
- **Température du détergent** : attendre que le thermostat STC1000 ait atteint 80 °C avant de lancer un cycle de lavage complet. Un détergent froid est moins efficace. Un touilleur pourrait aider à homogénéiser la température de la cuve, mais en pratique la turbulence générée par la pompe de circulation pendant les cycles de détergent suffit à maintenir la solution bien mélangée.
- **Renouvellement des produits** : utiliser les modes `Vidange` et `Rempl.` pour renouveler les solutions en fin de saison ou selon la fréquence recommandée par le fournisseur des produits.
- **Vérification des têtes de lavage** : s'assurer que les têtes sont bien encliquetées sur les plongeurs avant chaque cycle. Une tête mal connectée entraîne une fuite et un mauvais lavage.

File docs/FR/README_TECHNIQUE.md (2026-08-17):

# kegwasher — README Technique

> Ce projet est un fork de [vieuxsinge/kegwasher](https://github.com/vieuxsinge/kegwasher)
> et de [Gummy35/kegwasher](https://github.com/Gummy35/kegwasher).
> Licence : GNU GPL v3.

Ce document couvre les choix techniques effectués au fil des trois générations du projet. Pour les instructions d'utilisation, voir [MANUEL_UTILISATION.md](MANUEL_UTILISATION.md).

---

## Table des matières

1. [Vue d'ensemble de l'architecture](#1-vue-densemble-de-larchitecture)
2. [Moteur de séquences par étapes](#2-moteur-de-séquences-par-étapes)
3. [Modèle de contrôle des actionneurs](#3-modèle-de-contrôle-des-actionneurs)
4. [Séquencement ordonné ouverture/fermeture — Gummy35 + Ecolab07](#4-séquencement-ordonné-ouverturefermeture--gummy35--ecolab07)
5. [Pré-initialisation des pins à HIGH — Ecolab07](#5-pré-initialisation-des-pins-à-high--ecolab07)
6. [Machine à états](#6-machine-à-états)
7. [Affichage LCD alterné — Gummy35 + Ecolab07](#7-affichage-lcd-alterné--gummy35--ecolab07)
8. [Encodeur rotatif : protection contre les valeurs négatives — Ecolab07](#8-encodeur-rotatif--protection-contre-les-valeurs-négatives--ecolab07)
9. [Persistance du mode sélectionné en EEPROM](#9-persistance-du-mode-sélectionné-en-eeprom)
10. [Mode test des actionneurs — Ecolab07](#10-mode-test-des-actionneurs--ecolab07)
11. [Catalogue des modes de lavage](#11-catalogue-des-modes-de-lavage)
12. [Notes hardware](#12-notes-hardware)
13. [Dépendances](#13-dépendances)
14. [Simulation Wokwi](#14-simulation-wokwi)
15. [Schéma de câblage (Fritzing)](#15-schéma-de-câblage-fritzing)
16. [Limitations connues et travaux futurs](#16-limitations-connues-et-travaux-futurs)

---

## 1. Vue d'ensemble de l'architecture

Le firmware est un unique fichier `.ino` structuré autour de trois couches indépendantes :

```
┌─────────────────────────────────┐
│  Table des modes (MODES[])      │  Modes nommés → tableaux d'étapes
├─────────────────────────────────┤
│  Moteur de séquences            │  Étapes → configs actionneurs + timing
├─────────────────────────────────┤
│  Couche de contrôle actionneurs │  Bitmasks → écritures GPIO individuelles
└─────────────────────────────────┘
```

Ajouter un nouveau programme de lavage ne nécessite qu'un nouveau tableau `step_t` et une entrée dans `MODES[]`. Aucune modification de la logique de contrôle n'est requise.

---

## 2. Moteur de séquences par étapes

Chaque programme de lavage est exprimé comme un tableau de structs `step_t` :

```c
typedef struct step_s {
  unsigned int  config;   // masque de bits des actionneurs à activer
  unsigned long duration; // durée de maintien de cette configuration (secondes)
} step_t;
```

Le tableau est terminé par la valeur sentinelle `{CONFIG_END, 0}` (où `CONFIG_END == 0`), ce qui permet à `run_update()` de détecter la fin de séquence sans paramètre de longueur.

À l'exécution, `step_set(index)` applique la configuration des vannes via `controls_set()` (bloquant), puis enregistre `step_start_time` après la fin des transitions. `run_update()` est appelé à chaque itération de `loop()` et passe à l'étape suivante dès que `seconds() - step_start_time >= step.duration`.

Enregistrer `step_start_time` après les transitions garantit que la durée déclarée de chaque étape est mesurée à partir du moment où les vannes sont réellement dans leur état cible, et non avant le délai bloquant. Le même principe s'applique à `mode_start_time`, enregistré après `step_set(0)` dans `run()`.

L'utilisation des secondes horloge (via `millis() / 1000`) plutôt qu'un compteur rend le timing des étapes indépendant du temps d'exécution de `loop()`. Toutes les variables de temps utilisent `unsigned long` (32 bits sur AVR), cohérent avec `millis()` et à l'abri du débordement 16 bits qui affecterait `int` après ~9 heures.

---

## 3. Modèle de contrôle des actionneurs

Chacune des 9 sorties physiques se voit attribuer un bit unique en puissance de deux :

```c
#define CTRL_WATER          0b000000001
#define CTRL_CLEANER_IN     0b000000010
#define CTRL_SANITIZER_IN   0b000000100
#define CTRL_AIR            0b000001000
#define CTRL_CO2            0b000010000
#define CTRL_DRAIN          0b000100000
#define CTRL_CLEANER_OUT    0b001000000
#define CTRL_SANITIZER_OUT  0b010000000
#define CTRL_PUMP           0b100000000
```

Les configurations composites pour les séquences de lavage sont construites par OU de bits individuels :

```c
#define CONFIG_CLEAN  (CTRL_PUMP + CTRL_CLEANER_IN + CTRL_CLEANER_OUT)
```

Cette représentation est compacte, lisible et facilement extensible. Ajouter un 10e actionneur ne nécessite qu'un nouveau bit et une nouvelle pin — aucune modification structurelle.

Le mode test utilise délibérément des bits `CTRL_*` bruts (un actionneur à la fois) plutôt que des valeurs composites `CONFIG_*`, ce qui le rend utile pour diagnostiquer le comportement de chaque vanne individuellement.

---

## 4. Séquencement ordonné ouverture/fermeture — *Gummy35* + *Ecolab07*

Le firmware original commutait tous les actionneurs simultanément sans délai, avec des valeurs `HIGH`/`LOW` brutes. Gummy35 a entièrement refactorisé `controls_set_state()`, introduisant trois changements.

**Constantes logiques nommées** remplaçant les `HIGH`/`LOW` bruts :
```c
#define VALVE_CLOSE HIGH
#define VALVE_OPEN  LOW
```
Cela rend la logique active-low des relais explicite à chaque point d'appel.

**Ordre par direction** — les actionneurs sont désormais ouverts et fermés dans un ordre soigneusement choisi :

Ordre de fermeture (sources de pression d'abord, puis sorties) : pompe → eau/CO₂/air → entrées liquide → voies de retour → caniveau (en dernier, pour que la pression résiduelle puisse s'échapper).

Ordre d'ouverture (chemin libre avant la pression) : caniveau/retours → entrées liquide → pompe (aspire le liquide, réduisant la pression d'entrée) → air → CO₂ → eau (en dernier — la contre-pression de la pompe empêche le reflux dans les cuves).

Cet ordre prévient les pics de pression qui piègent le liquide dans les lignes lors de la fermeture, le reflux d'eau ou de produits chimiques dans les lignes CO₂ ou air lors de l'ouverture, et la cavitation de la pompe.

**Délai inter-actionneur à la fermeture** augmenté de 0 ms à 200 ms, correspondant au délai d'ouverture déjà présent dans l'original :

```c
// avant (Vieuxsinge)
controls_set_state(~config, HIGH, 0);   // fermeture : sans délai
controls_set_state(config,  LOW,  200); // ouverture : 200 ms

// après (Gummy35)
controls_set_state(~config, VALVE_CLOSE, 200); // fermeture : 200 ms
controls_set_state(config,  VALVE_OPEN,  200); // ouverture : 200 ms
```

**Aussi modifié par Gummy35** : `CONFIG_FILL_SANITIZER` et `CONFIG_FILL_CLEANER` avaient `CTRL_PUMP` supprimé (remplissage par pression du réseau uniquement). Cela a été rétabli dans le fork ecolab07 — la pompe est nécessaire pour faire circuler l'eau à travers le fût et la renvoyer dans la cuve via les vannes de retour (`CTRL_SANITIZER_OUT` / `CTRL_CLEANER_OUT`). Les vannes d'entrée (`CTRL_SANITIZER_IN` / `CTRL_CLEANER_IN`) sont orientées dans le mauvais sens pour ce chemin d'écoulement et ne sont pas utilisées lors du remplissage.

**Ecolab07 — logique de transition minimale** : `controls_set_state()` a été découpée en `close_actuators()` et `open_actuators()`, et `controls_set()` a été réécrite pour ne toucher que les actionneurs qui changent réellement d'état :

```c
unsigned int previous_config = 0;  // suit la configuration active

void controls_set(unsigned int config)
{
  unsigned int to_close = previous_config & ~config;
  unsigned int to_open  = config & ~previous_config;

  close_actuators(to_close);
  open_actuators(to_open);

  previous_config = config;
}
```

`previous_config & ~config` isole les actionneurs qui étaient ouverts et ne sont plus nécessaires. `config & ~previous_config` isole les actionneurs nécessaires qui n'étaient pas encore ouverts. Les actionneurs présents dans les deux configurations ne sont pas touchés. Trois bénéfices :

- **Courant d'appel** : seuls les relais qui changent vraiment d'état commutent, jamais les 9 simultanément.
- **Précision du timing** : le délai de 200 ms ne s'applique qu'aux actionneurs qui bougent, donc les transitions entre configurations similaires (ex. `CONFIG_CLEAN` → `CONFIG_CLEAN_PURGE`, qui partagent `CTRL_CLEANER_OUT`) sont plus rapides.
- **Sécurité de `CONFIG_WARNING` / `CONFIG_WAIT` par conception** : ces pseudo-configs ont les bits 10 et 11, hors de la plage des 9 bits d'actionneurs réels. `to_close` et `to_open` masquent naturellement ces bits — aucun actionneur n'est jamais déclenché, quelle que soit la valeur de `previous_config`.

---

## 5. Pré-initialisation des pins à HIGH — *Ecolab07*

La carte relais utilise une **logique active-low** : un signal LOW sur une pin de contrôle active le relais et ouvre la vanne. Les pins GPIO de l'Arduino sont en haute impédance par défaut au démarrage, ce que la carte relais tire à LOW — activant brièvement tous les relais avant l'appel de `pinMode(OUTPUT)` dans `setup()`.

Cela provoque un pic de courant d'appel non contrôlé (9 relais commutant simultanément) et, plus grave, une ouverture momentanée de toutes les vannes.

Le correctif consiste à écrire `HIGH` sur chaque pin *avant* d'appeler `pinMode()` :

```c
// Pré-forcer HIGH avant de configurer en sortie pour éviter
// le glitch LOW bref qui activerait tous les relais au démarrage
digitalWrite(PIN_VALVE_AIR, HIGH);
// ... toutes les autres pins vannes et pompe ...
pinMode(PIN_VALVE_AIR, OUTPUT);
// ...
```

Sur les Arduino AVR, `digitalWrite()` sur une pin encore en mode entrée écrit dans le registre de pull-up, ce qui ne produit pas de glitch LOW. La transition vers le mode `OUTPUT` part donc d'un niveau HIGH engagé, maintenant tous les relais désactivés.

---

## 6. Machine à états

La boucle principale dispatch sur un enum `state_t` :

```
STATE_SELECT → STATE_SELECT_UPDATE ──────────────────────┐
                     │ (appui bouton)                     │
                     ▼                                    │
               STATE_RUN                                  │
                     │                                    │
                     ▼                                    │
             STATE_RUN_UPDATE ──── (appui bouton) ──► STATE_CANCEL ─┐
                     │ (CONFIG_END)                                  │
                     ▼                                               │
             STATE_TERMINATE ──────────────────────────────────────►┘
                                                    (tous → STATE_SELECT)
```

Chaque état a une fonction gestionnaire dédiée. Les transitions sont écrites comme des affectations à la variable globale `state`, sur laquelle la prochaine itération de `loop()` va dispatcher. Cela maintient chaque gestionnaire petit et à responsabilité unique.

---

## 7. Affichage LCD alterné — *Gummy35* + *Ecolab07*

Pendant un cycle en cours, la ligne 1 du LCD alterne entre deux informations sur une cadence `LED_BLINK_PERIOD` (2 s) :

- **Première moitié de la période** : le label de l'étape en cours — ex. `Detergent`, `Purge air`
- **Seconde moitié de la période** : le nom du mode — ex. `Lavage + CO2`

La LED clignote en synchronisation avec cette alternance, fournissant un battement visible qui confirme aussi que l'Arduino tourne toujours.

```c
if( mode_running_time % LED_BLINK_PERIOD < LED_BLINK_PERIOD/2 ) {
    digitalWrite(PIN_LED, HIGH);
    lcd.setCursor(0, 0);
    lcd_printf(resolve_label(MODES[mode].steps[step].config));
}
else {
    digitalWrite(PIN_LED, LOW);
    lcd.setCursor(0, 0);
    lcd_printf(MODES[mode].name);
}
```

**Gummy35** a introduit cet affichage alterné et résolvait les labels via une variable globale `config_label` écrite dans `controls_set_state()`. **Ecolab07** a remplacé cela par `resolve_label()`, une fonction pure retournant un `const char*` vers un littéral en Flash sans effets de bord. La variable globale est supprimée — le label est résolu à la demande directement depuis la config de l'étape courante.

---

## 8. Encodeur rotatif : protection contre les valeurs négatives — *Ecolab07*

La librairie `RotaryEncoder` retourne une position entière signée qui décrémente en dessous de zéro quand l'encodeur est tourné dans le sens anti-horaire au-delà de la position 0. Une opération modulo naïve en C produit des résultats négatifs pour des opérandes négatifs (le signe suit le dividende), ce qui produirait un index invalide dans `MODES[]`.

**Première approche** — ajouter `MODES_NUMBER` avant le modulo :
```c
new_mode = (pos + MODES_NUMBER) % MODES_NUMBER;
```
Fonctionne correctement pour un tour complet anti-horaire (ex. `pos = -3` avec `MODES_NUMBER = 11` donne `8` ✅), mais échoue silencieusement quand `pos` est plus négatif que `-MODES_NUMBER` (ex. `pos = -14` donne `-3` ❌, car `(-14 + 11) % 11 = -3` en C).

**Approche actuelle** — double modulo :
```c
new_mode = ((pos % MODES_NUMBER) + MODES_NUMBER) % MODES_NUMBER;
```
`pos % MODES_NUMBER` réduit d'abord toute valeur dans `(-MODES_NUMBER, MODES_NUMBER)`, puis l'addition de `MODES_NUMBER` la rend positive, et le dernier `% MODES_NUMBER` la ramène dans `[0, MODES_NUMBER - 1]`. Correct pour toute valeur de `pos`, quel que soit le nombre de tours anti-horaires effectués.

---

## 9. Persistance du mode sélectionné en EEPROM

L'index du dernier mode sélectionné est écrit à l'adresse EEPROM `0` au lancement d'un cycle (uniquement si la valeur a changé, pour limiter l'usure en écriture) :

```c
int saved_mode = EEPROM.read(EEPROM_ADDRESS_MODE);
if( mode != saved_mode ) {
    EEPROM.write(EEPROM_ADDRESS_MODE, mode);
}
```

Au démarrage, la valeur stockée est lue et clampée à la plage valide :

```c
mode = constrain(mode, 0, MODES_NUMBER - 1);
```

Le clampage gère le cas où l'EEPROM contient `0xFF` (état effacé) ou un index obsolète d'une version firmware avec moins de modes.

---

## 10. Mode test des actionneurs — *Ecolab07*

Le mode test actionne chacun des 9 actionneurs individuellement pendant 1 seconde, dans l'ordre physique de la carte de relais, avec un intervalle de 1 seconde entre chaque impulsion.

**Intention de conception** : le mode test est implémenté entièrement comme un tableau `step_t` (`STEPS_TEST_ACTUATORS`), utilisant le même moteur de séquences que tous les autres modes. Aucun code spécial n'a été ajouté à la couche de contrôle.

Chaque étape utilise un bit `CTRL_*` brut plutôt qu'une valeur composite `CONFIG_*`, donc exactement un relais claque par étape. Cela permet de vérifier chaque vanne facilement à l'oreille ou en observant le circuit.

Deux pseudo-configurations spéciales sont introduites exclusivement pour ce mode :

| Constante | Bit | Rôle |
|---|---|---|
| `CONFIG_WARNING` | bit 10 | Affiche un prompt de sécurité (`Cuves vides ?`) avant le premier déclenchement de relais. Aucun actionneur n'est activé. |
| `CONFIG_WAIT` | bit 11 | Étape d'attente entre les impulsions : `controls_set(CONFIG_WAIT)` ferme tout (les bits 0–9 sont tous à zéro dans le masque), produisant un état OFF propre entre chaque actionnement individuel. |

Les deux bits sont hors de la plage 9 bits des actionneurs réels, ils ne peuvent donc pas entrer accidentellement en collision avec une sortie physique.

---

## 11. Catalogue des modes de lavage

| Mode | Tableau | Durée | Gummy35 | Ecolab07 |
|---|---|---|---|---|
| `Lavage + CO2` | `STEPS_WASH_KEG_PRESSURIZE` | 330 s | ✅ étape CO₂ | |
| `Lavage sans CO2` | `STEPS_WASH_KEG` | 320 s | | |
| `Detergent seul` | `STEPS_DETER_KEG` | 180 s | ✅ ajouté | |
| `CO2` | `STEPS_KEG_PRESSURIZE` | 50 s | ✅ ajouté | |
| `Desinf. + CO2` | `STEPS_SANITIZE_KEG_PRESSURIZE` | 190 s | ✅ ajouté | |
| `Vidange fut` | `STEPS_DRAIN_KEG` | 70 s | | |
| `Vidange desinf.` | `STEPS_DRAIN_SANITIZER` | 200 s | | |
| `Vidange deter.` | `STEPS_DRAIN_CLEANER` | 200 s | | |
| `Rempl. desinf.` | `STEPS_FILL_SANITIZER` | 120 s | | |
| `Rempl. deter.` | `STEPS_FILL_CLEANER` | 120 s | | |
| `Test vannes` | `STEPS_TEST_ACTUATORS` | 24 s | | ✅ ajouté |

---

## 12. Notes hardware

### Carte de relais — logique active-low
La carte de relais 16 canaux utilise des entrées active-low. Toutes les pins de contrôle sont pré-forcées à HIGH au démarrage (voir §5) pour éviter tout actionnement involontaire.

### Protection par diodes roue libre
Les électrovannes sont des charges inductives. Sans protection, le pic de surtension à la désactivation d'une vanne peut détruire les contacts des relais. Une diode roue libre 1N4148 est placée aux bornes de chaque vanne, le plus près possible de la sortie du relais.

### SSR pour la résistance chauffante du détergent
La résistance chauffante (thermoplongeur) dans la cuve de détergent est commutée par un relais statique (SSR) 40 A, piloté par le thermostat STC1000. L'élément de 3500 W d'origine a été remplacé par **2500 W** pour éviter de déclencher le disjoncteur sur des circuits partagés — le chauffage est plus lent mais reste dans la limite de courant permanent du disjoncteur. Le SSR est équipé d'un **radiateur et d'un ventilateur 12 V** (amélioration Ecolab07) pour éviter l'emballement thermique lors des longues sessions de chauffage.

### Arrêt d'urgence via contacteur
La conception originale connectait le bouton d'arrêt d'urgence directement dans le circuit de charge. Ecolab07 a remplacé cela par un **contacteur** piloté par le bouton coup-de-poing, de sorte que le bouton ne commute qu'une bobine à faible courant plutôt que le courant de charge total de la machine. Cela améliore la longévité du bouton et est plus sûr dans un environnement humide.

### Shield à bornier à vis pour Arduino
Ecolab07 a ajouté un **shield à bornier à vis** sur l'Arduino, équipé d'une zone de prototypage intégrée. Cela permet :
- de monter proprement la résistance de limitation de courant de la LED sur la platine
- de terminer tous les câbles externes sur des borniers à vis plutôt que sur des connecteurs Dupont, améliorant la fiabilité mécanique dans un environnement soumis aux vibrations et à l'humidité.

### Rampes de bus en sortie des relais
Ecolab07 a ajouté des **rampes de bus (bus bars)** côté sortie des relais pour simplifier le câblage des électrovannes. Chaque bus regroupe le fil de retour 12 V commun pour un ensemble de vannes, réduisant la complexité du câblage point à point et améliorant la lisibilité du boîtier.

### Étiquetage des composants
Tous les composants à l'intérieur du boîtier sont identifiés par des étiquettes adhésives. Cela rend le diagnostic de pannes et la maintenance accessibles sans avoir besoin de consulter le schéma de câblage.

---

## 13. Dépendances

| Librairie | Version testée | Utilisation |
|---|---|---|
| `Bounce2` | any | Anti-rebond du bouton |
| `LiquidCrystal_I2C` | 1.1.2 | Pilote LCD I²C |
| `RotaryEncoder` | any | Lecture de l'encodeur rotatif |

**`LiquidCrystal_I2C`** — auteur : Frank de Brabander, mainteneur : Marco Schwartz, dépôt : [github.com/johnrickman/LiquidCrystal_I2C](https://github.com/johnrickman/LiquidCrystal_I2C). Installer via le gestionnaire de librairies de l'IDE Arduino en recherchant `LiquidCrystal I2C` — cela installe la version 1.1.2, utilisée dans ce projet et fonctionnelle sans modification. Il existe plusieurs autres forks de cette librairie sous des noms similaires ; utiliser le mauvais peut provoquer des erreurs de compilation ou un comportement d'affichage incorrect.

---

## 14. Simulation Wokwi

Une simulation complète du circuit est disponible à :
**[https://wokwi.com/projects/464738080652364801](https://wokwi.com/projects/464738080652364801)**

La simulation inclut l'Arduino Uno, l'afficheur LCD I²C, la carte de relais (logique active-low), la LED témoin, le buzzer, l'encodeur rotatif et le bouton action. Les électrovannes sont représentées par des LEDs avec leurs labels, permettant la vérification visuelle de chaque séquence d'actionnement.

Le sketch complet fonctionne sans modification dans le simulateur.

**Limitations connues de Wokwi par rapport au hardware réel :**
- Les secondes s'écoulent plus lentement que dans la réalité — Wokwi ne simule pas le temps horloge à vitesse 1:1, donc les durées de cycle paraissent plus longues que déclaré.
- La logique active-low de la carte de relais est simulée avec une polarité inversée — vérifier que les defines `VALVE_OPEN`/`VALVE_CLOSE` correspondent à votre carte relais physique avant de flasher sur le hardware.

---

## 15. Schéma de câblage (Fritzing)

Un schéma de câblage Fritzing détaillé est fourni dans le dépôt (`fritzing/kegwasher.fzz` et `fritzing/kegwasher.png`). Le schéma reflète la disposition physique réelle des composants dans le boîtier et met en évidence quatre zones distinctes :

- **Composants déportés** : afficheur LCD et bouton action câblés sur la façade
- **Bloc sécurité** : bouton d'arrêt d'urgence coup-de-poing et contacteur
- **Prises de puissance** : points de connexion du thermoplongeur et de la pompe
- **Zone hydraulique** : câblage des électrovannes et bus bars en sortie des relais

Le fichier source `.fzz` est inclus pour quiconque souhaite modifier ou étendre le schéma.

---

## 16. Limitations connues et travaux futurs

### Temps affiché vs temps réel
Le délai de 200 ms inter-actionneur dans `close_actuators()` et `open_actuators()` est un appel `delay()` bloquant. Pendant les transitions, `loop()` ne tourne pas, donc les secondes affichées s'accumulent légèrement plus lentement que les secondes réelles. Le surcoût par transition est proportionnel au nombre d'actionneurs qui changent d'état (0–9 relais × 200 ms). Pour les modes les plus longs, cela ajoute environ 15 s de dérive sur un cycle de 5 min 35 s.

La branche `feature/nonblocking-timers` résout ce point en mesurant la durée des transitions avec `millis()` et en la soustrayant du temps affiché.

### Polling de l'encodeur et du bouton
L'encodeur et le bouton sont pollés dans la boucle principale (`menuselect.tick()`, `buttonAction.update()`). Pendant les transitions bloquantes, les appuis sur le bouton peuvent être manqués s'ils se produisent dans une fenêtre de 200 ms.

La branche `feature/rotary-interrupts` résout ce point en migrant la gestion de l'encodeur et du bouton vers des interruptions Pin Change (PCINT), rendant la détection des entrées indépendante du timing de la boucle.

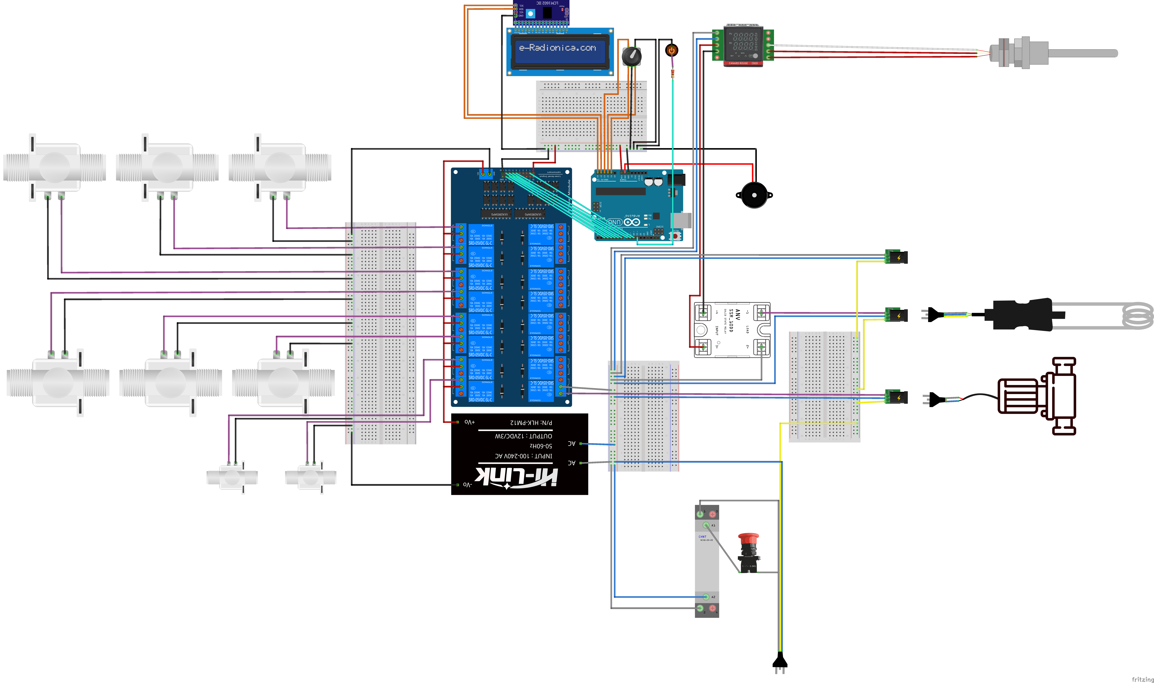
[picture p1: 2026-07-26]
fritzing/kegwasher.png

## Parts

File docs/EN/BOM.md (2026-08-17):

# Bill of Materials — Keg Washer / Laveuse de fûts

> This BOM is based on the original [vieuxsinge/kegwasher](https://github.com/vieuxsinge/kegwasher) component list, updated to reflect the changes made in this fork.
> Prices are indicative and may have changed. All prices are excluding VAT (HT).

---

> Cette BOM est basée sur la liste de composants originale de [vieuxsinge/kegwasher](https://github.com/vieuxsinge/kegwasher), mise à jour pour refléter les changements apportés dans ce fork.
> Les prix sont indicatifs et ont pu évoluer. Tous les prix sont hors taxes (HT).

---

## Structure / Châssis

| Composant | Fournisseur | Qté | PU (HT) | Total (HT) |
|---|---|---:|---:|---:|
| Cornière et carré acier | Ferrailleur | 1 | 80,00 € | 80,00 € |
| Peinture acier | Leroy Merlin | 1 | 30,00 € | 30,00 € |
| Roulette | Récup | 4 | 10,00 € | 40,00 € |
| Boîtier électrique plastique | Leroy Merlin | 1 | 37,00 € | 37,00 € |
| **Sous-total** | | | | **187,00 €** |

---

## Plomberie / Hydraulique

| Composant | Fournisseur | Qté | PU (HT) | Total (HT) |
|---|---|---:|---:|---:|
| Têtes de lavage | Maisonneuve | 2 | 52,00 € | 104,00 € |
| Pompe Novax 20B | [Canard rouge](https://microbrassage.com) | 1 | 79,17 € | 79,17 € |
| Électrovanne solénoïde inox 3/4'' 12V | [Amazon](https://www.amazon.fr/U-S-Solid-Électrovanne-Normalement-entraînement/dp/B00DQ24GS6/) | 6 | 26,46 € | 158,76 € |
| Électrovanne solénoïde inox 1/2'' 12V | [Amazon](https://www.amazon.fr/U-S-Solid-%C3%89lectrovanne-Normalement-entra%C3%AEnement/dp/B00APDA6Z6/) | 2 | 26,66 € | 53,32 € |
| Tuyau Thermoclean 100 19mm × 20m | [Raccords pro](http://www.raccordspro.com/fr/553-tuyau-thermoclean-100.html) | 1 | 174,20 € | 174,20 € |
| Tuyau crystal 12mm × 5m | Leroy Merlin | 1 | 9,08 € | 9,08 € |
| Clapet antiretour 3/4'' inox *(×2 — départ produit cuves)* | [Canard rouge](https://microbrassage.com/produits/clapet-anti-retour-3-4-bsp/) | 2 | 46,67 € | 93,34 € |
| Clapet antiretour 1/2'' inox *(sortie pompe + ligne gaz)* | [Pompes H2O](https://www.pompes-h2o.com) | 2 | 36,83 € | 73,66 € |
| Raccord gardena 3/4'' M laiton | Leroy Merlin | 1 | 3,75 € | 3,75 € |
| Raccord cannelé 3/4'' M inox | [Canard rouge](https://microbrassage.com) | 16 | 3,75 € | 60,00 € |
| Raccord cannelé 3/4'' F inox | [Canard rouge](https://microbrassage.com) | 5 | 4,08 € | 20,40 € |
| Raccord cannelé 1/2'' M inox | [Canard rouge](https://microbrassage.com) | 2 | 3,00 € | 6,00 € |
| Coude inox 1/2'' F/F | [Canard rouge](https://microbrassage.com) | 1 | 2,20 € | 2,20 € |
| Coude inox 3/4'' F/F | [Canard rouge](https://microbrassage.com) | 2 | 3,54 € | 7,08 € |
| Coude inox 3/4'' M/F | [Canard rouge](https://microbrassage.com) | 2 | 3,67 € | 7,34 € |
| Té inox 3/4'' F | [Canard rouge](https://microbrassage.com) | 7 | 3,92 € | 27,44 € |
| Té inox 1/2'' F | [Canard rouge](https://microbrassage.com) | 1 | 3,08 € | 3,08 € |
| Réduction 3/4'' M → 1/2'' M | [Canard rouge](https://microbrassage.com) | 1 | 2,00 € | 2,00 € |
| Mamelon inox 3/4'' M/M | [Canard rouge](https://microbrassage.com) | 10 | 2,21 € | 22,10 € |
| Mamelon inox 1/2'' M/M | [Canard rouge](https://microbrassage.com) | 3 | 1,83 € | 5,49 € |
| Bobine 3/4'' | [Canard rouge](https://microbrassage.com) | 4 | 3,21 € | 12,84 € |
| Colliers inox pour Thermoclean | [Canard rouge](https://microbrassage.com) | 25 | 0,79 € | 19,75 € |
| Colliers inox pour crystal | [Canard rouge](https://microbrassage.com) | 2 | 0,75 € | 1,50 € |
| Cuve inox 50L (Bergland) | Bergland | 2 | 35,21 € | 70,42 € |
| Écrou 1'' pour thermoplongeur | [Canard rouge](https://microbrassage.com) | 1 | 2,83 € | 2,83 € |
| Kit d'étanchéité 1'' | [Canard rouge](https://microbrassage.com) | 1 | 7,67 € | 7,67 € |
| Kit d'étanchéité 3/4'' | [Canard rouge](https://microbrassage.com) | 4 | 3,67 € | 14,68 € |
| Kit d'étanchéité 1/2'' (sonde température) | [Canard rouge](https://microbrassage.com) | 1 | 3,00 € | 3,00 € |
| Écrou 3/4'' | [Canard rouge](https://microbrassage.com) | 4 | 2,16 € | 8,64 € |
| Écrou 1/2'' | [Canard rouge](https://microbrassage.com) | 1 | 1,92 € | 1,92 € |
| Emporte-pièce 1'' | [Canard rouge](https://microbrassage.com) | 1 | 13,75 € | 13,75 € |
| Emporte-pièce 3/4'' | [Canard rouge](https://microbrassage.com) | 1 | 11,88 € | 11,88 € |
| Détendeur intermédiaire air comprimé | Leroy Merlin | 1 | 33,25 € | 33,25 € |
| Raccord rapide air comprimé M | Leroy Merlin | 1 | 3,33 € | 3,33 € |
| Raccord rapide air comprimé F | Leroy Merlin | 1 | 9,92 € | 9,92 € |
| **Sous-total** | | | | **~1 136,83 €** |

> ⚠️ Les prix des clapets antiretour ont été mis à jour par rapport à l'original Vieuxsinge (2 clapets 3/4'' ajoutés au départ produit de chaque cuve).

---

## Électronique

| Composant | Fournisseur | Qté | PU (HT) | Total (HT) | Note |
|---|---|---:|---:|---:|---|
| Arduino Uno | [Semageek](https://boutique.semageek.com) | 1 | 16,25 € | 16,25 € | |
| Terminal screw shield pour Arduino Uno | AliExpress | 1 | ~5,00 € | 5,00 € | ✨ ajout ecolab07 |
| Carte 16 relais 12V active-low | [Semageek](https://boutique.semageek.com) | 1 | 25,00 € | 25,00 € | |
| Diodes 1N4148 | [Semageek](https://boutique.semageek.com) | 16 | — | 0,83 € | 16 diodes montées sur les sorties relais |
| Câbles dupont | [Semageek](https://boutique.semageek.com) | 3 | 3,95 € | 11,85 € | |
| Alimentation 230V → 12V CC 120W | [Amazon](https://www.amazon.fr/IKSACE-Transformateur-Alimentation-Adaptateur-bande/dp/B074V1RT3Q) | 1 | 13,32 € | 13,32 € | |
| Rampes de bus (bus bars) | Récup | — | — | — | ✨ ajout ecolab07 |
| Écran LCD I²C 16×2 | [Amazon](https://www.amazon.fr/gp/product/B01N3B8JMN) | 1 | 6,67 € | 6,67 € | |
| Encodeur rotatif avec bouton | [Semageek](https://boutique.semageek.com/fr/896-encodeur-rotatif-24-positions-avec-validation-knob.html) | 1 | 4,50 € | 4,50 € | |
| Bouton action avec LED | [Semageek](https://boutique.semageek.com/fr/207-boutons-poussoirs-lumineux) | 1 | 4,95 € | 4,95 € | ou voyant lumineux vissable |
| Buzzer piézo passif | [Amazon](https://www.amazon.fr/GLOGLOW-électronique-tonalité-Piézo-électrique-Sonnerie/dp/B07F5LB8K9) | 1 | 5,58 € | 5,58 € | |
| Bouton arrêt d'urgence coup-de-poing | [Amazon](https://www.amazon.fr/gp/product/B00H3CY432) | 1 | 2,31 € | 2,31 € | |
| Contacteur | Récup | 1 | — | — | ✨ ajout ecolab07 — piloté par le bouton coup-de-poing |
| Relais statique (SSR) 40A | [Canard rouge](https://microbrassage.com) | 1 | 7,50 € | 7,50 € | |
| Radiateur pour SSR | Récup | 1 | — | — | ✨ ajout ecolab07 |
| Ventilateur 12V pour SSR | Récup | 1 | — | — | ✨ ajout ecolab07 |
| Régulateur de température CR20 | [Canard rouge](https://microbrassage.com/produits/pid-cr20-pour-ssr/) | 1 | 29,00 € | 29,00 € | ✨ remplace le STC1000 de Vieuxsinge |
| Résistance chauffante 2500W ULWD + kit montage | [Canard rouge](https://microbrassage.com/produits/resistance-chauffante-v2-25kw-ulwd-avec-kit-de-montage/) | 1 | 50,00 € | 50,00 € | ✨ remplace le 3500W de Vieuxsinge |
| Sonde température inox NTC | [Guilcor](https://sondes-thermiques.fr/sonde-a-thermistance-ntc/3692-sonde-ntc-10k-raccord-g12-plongeur-50-a-400mm.html) | 1 | 9,80 € | 9,80 € | |
| Câble 2 fils 0,75mm² × 10m | Leroy Merlin | 1 | 5,83 € | 5,83 € | |
| Câbles 1 fil 1,5mm² (plusieurs couleurs) | Récup | — | — | — | |
| Câble 3 fils 2,5mm² souple × 5m | Leroy Merlin | 1 | 11,67 € | 11,67 € | |
| Prise 230V mâle étanche | Leroy Merlin | 1 | 8,42 € | 8,42 € | |
| Prise 230V femelle étanche | Leroy Merlin | 1 | 7,32 € | 7,32 € | |
| **Sous-total** | | | | **~235,80 €** | |

---

## Divers

| Composant | Fournisseur | Qté | PU (HT) | Total (HT) |
|---|---|---:|---:|---:|
| Frais de port estimés | | 1 | 60,00 € | 60,00 € |
| **Sous-total** | | | | **60,00 €** |

---

## Total estimé

| Catégorie | Total (HT) |
|---|---:|
| Structure / Châssis | 187,00 € |
| Plomberie / Hydraulique | ~1 136,83 € |
| Électronique | ~235,80 € |
| Divers | 60,00 € |
| **Total** | **~1 619,63 €** |

> Les composants marqués ✨ sont des ajouts ou substitutions par rapport à l'original Vieuxsinge.
> Les composants "Récup" sont comptés à 0 € — prévoir un supplément si achat neuf.
> Les prix ont pu évoluer depuis la rédaction de cette BOM.

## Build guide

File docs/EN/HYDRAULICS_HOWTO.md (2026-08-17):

# Hydraulics Assembly Guide — Keg Washer

> This guide is largely based on the hydraulic documentation from [vieuxsinge/kegwasher](https://github.com/vieuxsinge/kegwasher), with additions specific to this fork.
> License: GNU GPL v3.

---

# Guide d'assemblage hydraulique — Laveuse de fûts

> Ce guide est largement inspiré de la documentation hydraulique de [vieuxsinge/kegwasher](https://github.com/vieuxsinge/kegwasher), avec les ajouts spécifiques à ce fork.
> Licence : GNU GPL v3.

---

## Overview / Vue d'ensemble

The hydraulic circuit connects two product tanks (detergent and sanitizer), a mains water inlet, a compressed air inlet, a CO₂ inlet, a pump, two wash heads, and a drain outlet. The circuit is controlled by 9 solenoid valves.

Le circuit hydraulique relie deux cuves produits (détergent et désinfectant), une arrivée d'eau du réseau, une arrivée d'air comprimé, une arrivée de CO₂, une pompe, deux têtes de lavage et une évacuation au caniveau. Le circuit est contrôlé par 9 électrovannes.

📷 *[Photo: full hydraulic circuit overview]*
📷 *[Photo: vue d'ensemble du circuit hydraulique]*

---

## 1. Product tanks / Cuves produits

The product tanks are 50L Bergland stainless steel pots, well-known among homebrewers. Canard rouge sealing kits and barbed fittings provide simple, leak-free tank inlets and outlets.

Les cuves produits sont des marmites Bergland 50L en inox, bien connues des brasseurs amateurs. Des kits d'étanchéité Canard rouge et des raccords cannelés permettent de réaliser très simplement des entrées et sorties pour les produits.

Each tank has:
- 1 bottom outlet → liquid distributor (3/4'' barbed fitting + sealing kit)
- 1 upper inlet → product return from keg (3/4'' barbed fitting + sealing kit)
- 1 × 1'' fitting for the immersion heater (detergent tank only)
- 1 × 1/2'' fitting for the temperature probe (detergent tank only)

Chaque cuve dispose de :
- 1 sortie basse → distributeur de liquides (raccord cannelé 3/4'' + kit d'étanchéité)
- 1 entrée haute → retour produit depuis le fût (raccord cannelé 3/4'' + kit d'étanchéité)
- 1 piquage 1'' pour le thermoplongeur (cuve détergent uniquement)
- 1 piquage 1/2'' pour la sonde de température (cuve détergent uniquement)

Use a hole punch (emporte-pièce) sized for each fitting to make clean, round holes in the tank walls.

Utiliser un emporte-pièce de la taille adaptée à chaque raccord pour réaliser des perçages propres et ronds dans les parois des cuves.

📷 *[Photo: tank fittings and sealing kits]*
📷 *[Photo: raccords et kits d'étanchéité sur les cuves]*

---

## 2. Check valves at tank outlets / Clapets antiretour en sortie de cuves

**ecolab07 addition**: a 3/4'' stainless check valve is installed as close as possible to the outlet of each product tank. This prevents liquid from one tank from back-flowing into the other tank when the pump is running with different inlet valves open.

**Ajout ecolab07** : un clapet antiretour inox 3/4'' est installé au plus près de la sortie de chaque cuve produit. Cela évite qu'un liquide d'une cuve ne remonte dans l'autre cuve lorsque la pompe tourne avec différentes vannes d'entrée ouvertes.

Reference: [Clapet antiretour 3/4'' BSP — Canard rouge](https://microbrassage.com/produits/clapet-anti-retour-3-4-bsp/)

📷 *[Photo: check valve at tank outlet]*
📷 *[Photo: clapet antiretour en sortie de cuve]*

---

## 3. Liquid distributor / Distributeur de liquides

The bottom of each tank and the mains water inlet connect to a liquid distributor made from stainless steel tees: 3 inlets, 1 outlet. Each inlet has a solenoid valve that controls which liquid enters the distributor. The distributor outlet connects to the pump inlet.

Le bas de chaque cuve et l'arrivée d'eau du réseau sont reliés à un distributeur de liquides réalisé à base de tés en inox : 3 entrées et 1 sortie. Sur chaque entrée se trouve une électrovanne qui permet de choisir quel liquide entre dans le distributeur. La sortie du distributeur est reliée à l'entrée de la pompe.

📷 *[Photo: liquid distributor]*
📷 *[Photo: distributeur de liquides]*

---

## 4. Gas distributor / Distributeur de gaz

Like the liquid distributor, the machine has a 2-inlet gas distributor. Solenoid valves control which gas source (air or CO₂) is active. The gas distributor connects to the pump outlet. Intermediate pressure regulators can be fitted on each gas inlet to avoid having to adjust the compressor each time.

Comme pour les liquides, la laveuse est équipée d'un distributeur de gaz à 2 entrées. Les électrovannes permettent d'activer ou non l'arrivée d'air ou de CO₂. Le distributeur de gaz est relié à la sortie de la pompe. Les entrées gaz peuvent être équipées de détendeurs intermédiaires qui évitent de devoir régler le compresseur à chaque fois.

Recommended pressure for both air and CO₂: **2.5 bar**.

Pression recommandée pour l'air et le CO₂ : **2,5 bar**.

📷 *[Photo: gas distributor and pressure regulators]*
📷 *[Photo: distributeur de gaz et détendeurs]*

---

## 5. Check valves at pump / Clapets antiretour sur la pompe

Two check valves are critical:
- **Pump outlet**: prevents gas from flowing back through the pump in reverse when a gas valve is open.
- **Gas inlet** (just before the pump outlet tee): prevents liquid from flowing back into the gas lines.

**Do not skip these valves** — the original Vieuxsinge build destroyed several relay board outputs and pump seals before they were added.

Deux clapets antiretour sont indispensables :
- **Sortie de pompe** : évite que le gaz ne repasse dans la pompe en sens inverse quand une vanne gaz est ouverte.
- **Arrivée gaz** (juste avant le té de sortie de pompe) : évite que le liquide ne remonte dans les lignes de gaz.

**Ne pas omettre ces clapets** — le montage original Vieuxsinge a grillé plusieurs sorties de la carte de relais et des joints de pompe avant qu'ils ne soient ajoutés.

📷 *[Photo: check valves at pump]*
📷 *[Photo: clapets antiretour sur la pompe]*

---

## 6. Wash heads / Têtes de lavage

The pump outlet is split into 2 lines via a tee to feed two wash heads simultaneously. Wash heads are similar to keg couplers but used in reverse, with a larger outlet to allow cleaning liquid to flow through.

La sortie de la pompe est divisée en 2 tuyaux via un té pour alimenter les 2 têtes de lavage simultanément. Les têtes de lavage ressemblent à des têtes de tirage mais utilisées à l'envers, avec une sortie plus grande pour laisser passer le liquide de nettoyage.

The kegs are placed upside down (spear facing down) on the machine's upper support bars. The wash head connects to the spear and the keg body simultaneously.

Les fûts sont posés à l'envers (plongeur vers le bas) sur les barres de support de la partie haute de la machine. La tête de lavage se connecte simultanément sur le plongeur et sur le corps du fût.

📷 *[Photo: wash heads connected to kegs]*
📷 *[Photo: têtes de lavage connectées sur les fûts]*

---

## 7. Product collector / Collecteur de produits

The wash head outlets connect to a product collector: a tee assembly that works in reverse to the distributor — 1 inlet and 3 outlets. Each outlet has a solenoid valve:
- 2 return valves → back into the product tanks (upper inlet)
- 1 drain valve → to the floor drain

Les sorties des têtes de lavage sont reliées à un collecteur de produits. C'est un assemblage de tés qui fonctionne à l'inverse du distributeur : 1 entrée et 3 sorties. Sur chaque sortie se trouve une électrovanne :
- 2 vannes de retour → vers les cuves produits (entrée haute)
- 1 vanne de vidange → vers le caniveau

📷 *[Photo: product collector]*
📷 *[Photo: collecteur de produits]*

---

## 8. Hoses / Tuyaux

| Section | Hose type | Diameter | Notes |
|---|---|---|---|
| Product lines (tanks → pump → wash heads → collector) | Thermoclean 100 | 19 mm | Chemical-resistant, food-safe |
| Wash head connections | Clear crystal | 19 mm | More flexible than Thermoclean — easier keg handling |
| Gas lines (air, CO₂) | Clear crystal | 15 mm | |

| Section | Type de tuyau | Diamètre | Notes |
|---|---|---|---|
| Lignes produit (cuves → pompe → têtes → collecteur) | Thermoclean 100 | 19 mm | Résistant aux produits corrosifs, alimentaire |
| Connexions têtes de lavage | Cristal | 19 mm | Plus souple que le Thermoclean — manipulation des fûts facilitée |
| Lignes gaz (air, CO₂) | Cristal | 15 mm | |

---

## 9. Fittings / Raccords

All fittings are stainless steel and sealed with PTFE tape (teflon) for better resistance to corrosive products.

Tous les raccords sont en inox et étanchéifiés au téflon pour mieux supporter les produits corrosifs.

For drilling tank walls and fitting sealing kits, refer to the [Canard rouge sealing kit instructions](https://www.microbrassage.com/wp-content/uploads/2015/03/notice_kit_etancheite-.pdf).

Pour percer les cuves et fixer les kits d'étanchéité, consulter la [notice du kit d'étanchéité Canard rouge](https://www.microbrassage.com/wp-content/uploads/2015/03/notice_kit_etancheite-.pdf).

---

## 10. Detergent tank heater / Chauffage de la cuve détergent

The detergent tank is equipped with a 2500W ULWD immersion heater (low watt density — gentler on the element and the tank). It is controlled by the CR20 PID temperature controller from Canard rouge, set to maintain 80 °C.

La cuve de détergent est équipée d'un thermoplongeur ULWD 2500W (faible densité de puissance — plus doux pour l'élément et la cuve). Il est contrôlé par le régulateur PID CR20 de Canard rouge, réglé pour maintenir 80 °C.

> ⚠️ A 3500W element was used in the original Vieuxsinge build. This fork uses 2500W to avoid tripping the circuit breaker on shared circuits. Heating is slower but stays within the breaker's sustained current rating.

> ⚠️ Le montage original Vieuxsinge utilise un thermoplongeur de 3500W. Ce fork utilise 2500W pour éviter de déclencher le disjoncteur sur des circuits partagés. Le chauffage est plus lent mais reste dans la limite de courant permanent du disjoncteur.

References / Références :
- [Résistance chauffante V2 2,5kW ULWD + kit de montage — Canard rouge](https://microbrassage.com/produits/resistance-chauffante-v2-25kw-ulwd-avec-kit-de-montage/)
- [PID CR20 pour SSR — Canard rouge](https://microbrassage.com/produits/pid-cr20-pour-ssr/)

📷 *[Photo: immersion heater and CR20 controller]*
📷 *[Photo: thermoplongeur et régulateur CR20]*

---

## Safety notes / Consignes de sécurité

- Always work with the machine unpowered when modifying the hydraulic circuit.
- PTFE tape on all threaded stainless fittings — never leave a fitting dry.
- Check all connections for leaks before the first powered cycle. Run a plain water cycle first.
- Caustic soda (detergent) and peracetic acid (sanitizer) are corrosive. Wear gloves and eye protection when handling concentrates.
- Never mix the two products — they neutralise each other and can react violently at high concentrations.

- Toujours travailler machine hors tension lors de modifications du circuit hydraulique.
- Téflon sur tous les raccords filetés en inox — ne jamais laisser un raccord sec.
- Vérifier toutes les connexions pour détecter les fuites avant le premier cycle sous tension. Lancer d'abord un cycle à l'eau claire.
- La soude (détergent) et l'acide peracétique (désinfectant) sont corrosifs. Porter gants et lunettes lors de la manipulation des concentrés.
- Ne jamais mélanger les deux produits — ils se neutralisent et peuvent réagir violemment à haute concentration.

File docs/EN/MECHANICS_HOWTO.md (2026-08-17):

# Mechanics Assembly Guide — Keg Washer

> This guide is based on the structural documentation from [vieuxsinge/kegwasher](https://github.com/vieuxsinge/kegwasher).
> License: GNU GPL v3.

---

# Guide d'assemblage mécanique — Laveuse de fûts

> Ce guide est basé sur la documentation structurelle de [vieuxsinge/kegwasher](https://github.com/vieuxsinge/kegwasher).
> Licence : GNU GPL v3.

---

## Overview / Vue d'ensemble

The frame is built from welded steel angle iron and square tube, mounted on castors for mobility. It is divided into two levels:
- **Lower level**: product tanks and pump
- **Upper level**: support bars for kegs (placed upside down) and solenoid valve brackets

Le châssis est réalisé en cornières et tube carré acier soudés maison, monté sur roulettes pour la mobilité. Il se divise en deux niveaux :
- **Partie basse** : cuves produits et pompe
- **Partie haute** : barres de support pour les fûts (posés à l'envers) et supports des électrovannes

📷 *[Photo: full frame assembled]*
📷 *[Photo: châssis assemblé complet]*

---

## 1. Frame / Châssis

The frame is welded from steel angle iron (cornière) and square tube. No particular dimensions are imposed — adapt to your available space and keg height. Key constraints:

- Upper bars must be at a height compatible with the wash head connections (kegs upside down, spear facing down).
- Lower level must accommodate the two 50L tanks side by side with enough clearance for hose connections.
- The electronics enclosure is fixed to the side of the frame.

Le châssis est soudé en cornières et tube carré acier. Aucune dimension particulière n'est imposée — adapter à l'espace disponible et à la hauteur des fûts. Contraintes principales :

- Les barres supérieures doivent être à une hauteur compatible avec les connexions des têtes de lavage (fûts à l'envers, plongeur vers le bas).
- Le niveau inférieur doit accueillir les deux cuves 50L côte à côte avec suffisamment d'espace pour les connexions hydrauliques.
- Le boîtier électronique est fixé sur le côté du châssis.

📷 *[Photo: frame welding detail]*
📷 *[Photo: détail soudures du châssis]*

---

## 2. Surface treatment / Traitement de surface

After welding and grinding, apply an anti-rust steel paint to protect the frame from moisture and cleaning product splashes.

Après soudage et meulage, appliquer une peinture antirouille pour acier afin de protéger le châssis de l'humidité et des projections de produits de nettoyage.

📷 *[Photo: painted frame]*
📷 *[Photo: châssis peint]*

---

## 3. Castors / Roulettes

4 castors are fitted to the bottom of the frame for mobility. Use locking castors (at least 2) to prevent the machine from moving during operation.

4 roulettes sont fixées sous le châssis pour la mobilité. Utiliser des roulettes avec frein (au moins 2) pour éviter que la machine ne se déplace pendant le fonctionnement.

📷 *[Photo: castors fitted]*
📷 *[Photo: roulettes montées]*

---

## 4. Keg support bars / Barres de support des fûts

Horizontal bars on the upper level support the kegs placed upside down. Space them to match the keg diameter and ensure stable positioning during the wash cycle.

Des barres horizontales sur la partie haute supportent les fûts posés à l'envers. Les espacer selon le diamètre des fûts pour assurer un positionnement stable pendant le cycle de lavage.

📷 *[Photo: keg support bars with kegs in position]*
📷 *[Photo: barres de support avec fûts en position]*

---

## 5. Solenoid valve brackets / Supports des électrovannes

Small brackets or channels welded to the frame hold the solenoid valves in position and prevent hose strain. Route hoses through cable glands or conduits where possible to keep the installation tidy.

De petites gouttières ou pattes soudées au châssis maintiennent les électrovannes en position et évitent de mettre les tuyaux sous tension. Faire passer les câbles dans des gaines si possible pour soigner l'installation.

📷 *[Photo: valve brackets]*
📷 *[Photo: supports des électrovannes]*

---

## 6. Electronics enclosure / Boîtier électronique

The electronics enclosure (plastic IP-rated box) is fixed to the side of the frame. Position it:
- High enough to be away from splashes and floor puddles
- Accessible for front panel operation (LCD, encoder, action button, emergency stop)
- With cable entries at the bottom (keeps water ingress away from components)

Le boîtier électronique (coffret plastique avec indice de protection) est fixé sur le côté du châssis. Le positionner :
- Assez haut pour être à l'écart des projections et des flaques au sol
- Accessible pour le panneau de commande en façade (LCD, encodeur, bouton action, arrêt d'urgence)
- Avec les entrées de câbles en bas (éloigne l'humidité des composants)

Secure all cable runs to the frame with cable ties or conduit to prevent them from catching on kegs or other equipment.

Fixer tous les câbles au châssis avec des colliers ou des gaines pour éviter qu'ils ne se prennent dans les fûts ou d'autres équipements.

📷 *[Photo: electronics enclosure mounted on frame]*
📷 *[Photo: boîtier électronique monté sur le châssis]*

---

## 7. Cable management / Gestion des câbles

The many solenoid valve cables can be routed through flexible conduit fixed to the frame. This keeps the installation clean and protects cables from moisture and mechanical wear.

Les nombreux câbles des électrovannes peuvent être acheminés dans des gaines flexibles fixées au châssis. Cela soigne l'installation et protège les câbles de l'humidité et de l'usure mécanique.

📷 *[Photo: cable management / conduits]*
📷 *[Photo: gestion des câbles / gaines]*

---

## Safety notes / Consignes de sécurité

- All welding should be performed by a competent person with appropriate safety equipment.
- Grind all weld spatter smooth — sharp edges can damage hoses and injure operators.
- Ensure the frame is stable and does not rock before fitting tanks and equipment. Adjust castor height if needed.
- The frame must support the weight of two full 50L tanks (~50 kg each) plus the pump, electronics, and hose assembly.

- Toutes les soudures doivent être réalisées par une personne compétente avec les équipements de protection appropriés.
- Meuler les projections de soudure — les arêtes vives peuvent endommager les tuyaux et blesser les opérateurs.
- S'assurer que le châssis est stable et ne tangue pas avant de fixer les cuves et les équipements. Ajuster la hauteur des roulettes si nécessaire.
- Le châssis doit supporter le poids de deux cuves 50L pleines (~50 kg chacune) plus la pompe, l'électronique et le circuit hydraulique.

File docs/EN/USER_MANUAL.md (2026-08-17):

# User Manual — Automatic Keg Washer

> This project is a fork of [vieuxsinge/kegwasher](https://github.com/vieuxsinge/kegwasher)
> and [Gummy35/kegwasher](https://github.com/Gummy35/kegwasher).
> License: GNU GPL v3.

---

## Table of Contents

1. [Overview](#1-overview)
2. [Prerequisites](#2-prerequisites)
3. [Controls and display](#3-controls-and-display)
4. [Starting up and selecting a mode](#4-starting-up-and-selecting-a-mode)
5. [Mode descriptions](#5-mode-descriptions)
6. [During a wash cycle](#6-during-a-wash-cycle)
7. [End of cycle](#7-end-of-cycle)
8. [Cancelling a cycle](#8-cancelling-a-cycle)
9. [Emergency stop](#9-emergency-stop)
10. [After use](#10-after-use)
11. [Practical tips](#11-practical-tips)

---

## 1. Overview

The automatic keg washer cleans stainless steel kegs **without removing the spears**. Cleaning products are injected through wash heads and circulated inside the keg by a pump.

The machine can wash **2 kegs simultaneously**.

It is equipped with:
- 2 product tanks: **detergent** (2 % caustic soda, kept at 80 °C) and **sanitizer** (1 % peracetic acid)
- 1 mains water inlet
- 1 compressed air inlet
- 1 CO₂ inlet
- 1 drain outlet

A full wash cycle takes approximately **5 minutes 30 seconds**.

---

## 2. Prerequisites

Before starting any cycle, check the following:

- [ ] **Product tanks are filled** to the correct level (detergent and sanitizer)
- [ ] **Detergent tank is at temperature** (80 °C — check the STC1000 thermostat)
- [ ] **Water supply** is open
- [ ] **Compressed air supply** is open (recommended pressure: **2.5 bar**)
- [ ] **CO₂ supply** is open (recommended pressure: **2.5 bar**)
- [ ] **Kegs are connected** to the wash heads (spear facing down)
- [ ] **Drain outlet** is clear
- [ ] **Emergency stop button** is released (turn to unlock)

---

## 3. Controls and display

The machine has three controls on the front panel:

| Control | Function |
|---|---|
| **Rotary encoder** | Browse modes (rotate = change mode) |
| **Action button** | Confirm selected mode / cancel a running cycle |
| **Emergency stop button** | Immediate full power cut via contactor |

The **LCD screen** (2 lines × 16 characters) shows:
- Line 1: the name of the selected mode or the current step
- Line 2: cycle progress (elapsed time / total time)

The **LED** on the front panel:
- **Solid on**: waiting for selection
- **Blinking**: cycle in progress

The **buzzer** sounds:
- **1 beep**: cycle cancelled
- **3 beeps**: cycle completed normally

---

## 4. Starting up and selecting a mode

1. Power the machine on.
2. The screen shows `Mode :` on the first line and the name of the last used mode on the second *(the last mode is stored in EEPROM and restored after a power cut)*.
3. **Rotate the encoder** to browse the available modes.
4. **Press the action button** to launch the displayed mode.
5. The screen shows `Preparation` while the machine configures the solenoid valves, then the cycle begins.

---

## 5. Mode descriptions

> For the actuator sequence diagrams of each mode (which valves are active at each step), see the [Mode sequence diagrams (GRAFCET)](GRAFCET_ALL_MODES.md).

### Full wash modes

#### `Lavage + CO2` — 330 s (5 min 30)
Full wash cycle. Recommended for kegs that have contained beer.

| Phase | Duration | Description |
|---|---|---|
| Initial drain | 10 s | Residual contents flushed to drain |
| Initial rinse | 30 s | Water + air purge to remove coarse residue |
| Detergent (×3) | 75 s | Hot caustic soda circulation at 80 °C + air purge between each pass |
| Intermediate rinse (×3) | 60 s | Complete removal of detergent traces |
| Sanitizer (×3) | 65 s | Peracetic acid circulation + air purge between each pass |
| Final rinse + CO₂ purge | 40 s | Water + CO₂ purge to displace oxygen |
| CO₂ pressurisation | 10 s | Keg pressurised before filling |

✅ **Keg ready to fill directly.**

---

#### `Lavage sans CO2` — 320 s (5 min 20)
Same as the above but without the final CO₂ pressurisation step. The final purge uses compressed air.

Use this mode if CO₂ pressurisation is done separately, or if the keg will not be filled immediately.

---

#### `Detergent seul` — 180 s (3 min 00)
Detergent wash and rinses only — no sanitization, no CO₂.

Use for a quick clean between two closely-spaced uses, or when sanitization will be done in a separate step.

---

### Sanitization and pressurisation modes

#### `Desinf. + CO2` — 190 s (3 min 10)
Sanitization only, followed by a CO₂ purge and pressurisation.

Use on a keg that **has already been washed with detergent** in a previous session.

---

#### `CO2` — 50 s
CO₂ purge and pressurisation only — no chemicals.

Use to re-pressurise a clean keg that has been left open, or to displace residual air.

---

### Product tank maintenance modes

#### `Vidange fut` — 70 s (1 min 10)
Drains the keg to the drain outlet, followed by a long air purge to dry the lines.

Use to empty a keg before storage or return.

---

#### `Vidange desinf.` — 200 s (3 min 20)
Empties the **sanitizer tank** through the circuit to the drain via the pump.

Use at the end of a session to empty the sanitizer tank, or to renew the solution.

---

#### `Vidange deter.` — 200 s (3 min 20)
Empties the **detergent tank** through the circuit to the drain via the pump.

Use to renew the detergent solution or at the end of the season.

---

#### `Rempl. desinf.` — 120 s (2 min 00)
Fills the **sanitizer tank** with mains water. Water enters the keg via the water inlet, then is pumped back into the sanitizer tank through the return valve (`SANITIZER_OUT`).

> ⚠️ Make sure the tank is empty or has enough capacity before starting this mode.

---

#### `Rempl. deter.` — 120 s (2 min 00)
Fills the **detergent tank** with mains water. Water enters the keg via the water inlet, then is pumped back into the detergent tank through the return valve (`CLEANER_OUT`).

> ⚠️ Same precaution as for sanitizer refilling. Remember to add caustic soda after filling.

---

### Test mode

#### `Test vannes` — 24 s
Activates each actuator **individually** for 1 second, in the physical order of the relay board (left to right, top to bottom).

> ⚠️ **All tanks must be empty before running this mode.** The screen displays `Cuves vides ?` for 5 seconds at the start. Wait for this prompt and confirm before the test begins.

Use to verify wiring, diagnose a silent solenoid valve, or confirm correct assembly after build or repair.

Firing order: sanitizer return → drain → detergent return → air → CO₂ → sanitizer inlet → water → detergent inlet → pump.

---

## 6. During a wash cycle

- Line 1 of the screen shows the current step name (alternating with the mode name).
- Line 2 shows elapsed time and total cycle time.
- The LED blinks every 2 seconds.
- **Do not disconnect kegs during a cycle.**

---

## 7. End of cycle

When all steps have completed:
1. All solenoid valves close and the pump stops.
2. The LED turns off.
3. The screen displays `Termine`.
4. The buzzer sounds **3 beeps**.
5. The machine returns automatically to the selection menu.

---

## 8. Cancelling a cycle

Press the **action button** during a running cycle to cancel it immediately:
1. All solenoid valves close and the pump stops.
2. The screen displays `Annule`.
3. The buzzer sounds **1 beep**.
4. The machine returns to the selection menu.

> ⚠️ If a cycle is cancelled mid-run, the kegs and lines may contain product residue. Run a rinse cycle before filling the kegs.

---

## 9. Emergency stop

The **mushroom-head button** on the front panel cuts the main power via a contactor.

It acts on the **entire machine** (pump, solenoid valves, Arduino).

To reset: **turn the button** in the indicated direction until it clicks out.

> ⚠️ After an emergency stop, all solenoid valves return to their rest state (closed = safe). Check the circuit before restoring power.

---

## 10. After use

- Check that product tanks are at the right level for the next session.
- If the session is over for the day, product tanks can be left in place (they are designed to remain in circuit).
- Close the water, air, and CO₂ supplies if the machine will not be used for an extended period.
- Rinse and dry the wash heads.

---

## 11. Practical tips

- **Time efficiency**: washing (5 min) can run in parallel with filling already-clean kegs. This is the main advantage of automation.
- **Detergent temperature**: wait for the STC1000 thermostat to reach 80 °C before starting a full wash cycle. Cold detergent is significantly less effective. A stirrer could help homogenise the tank temperature, but in practice the turbulence generated by the circulation pump during detergent cycles is sufficient to keep the solution well mixed.
- **Product renewal**: use the `Vidange` and `Rempl.` modes to renew solutions at the end of the season or according to the product supplier's recommendations.
- **Wash head check**: make sure the wash heads are properly clicked onto the spears before each cycle. A loose connection causes leaks and poor cleaning results.

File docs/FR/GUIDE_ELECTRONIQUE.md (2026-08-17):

# Guide d'assemblage électronique — Laveuse de fûts

> Ce projet est un fork de [vieuxsinge/kegwasher](https://github.com/vieuxsinge/kegwasher)
> et de [Gummy35/kegwasher](https://github.com/Gummy35/kegwasher).
> Licence : GNU GPL v3.

Ce guide décrit l'assemblage du système de contrôle électronique, sous-système par sous-système, dans l'ordre de montage recommandé. Les références et sources des composants sont couvertes dans la [BOM](BOM.md) séparée.

> 📷 *Les emplacements photo sont signalés tout au long du document. Ajoutez vos propres images aux endroits indiqués.*

---

## Prérequis

> 💡 **Avant de commencer le montage**, vous pouvez tester le circuit complet dans le simulateur Wokwi : [https://wokwi.com/projects/464738080652364801](https://wokwi.com/projects/464738080652364801). La simulation inclut l'Arduino, le LCD, la carte de relais, l'encodeur, le bouton, le buzzer et des LEDs représentant chaque électrovanne. C'est un bon moyen de se familiariser avec le comportement du firmware avant de passer au câblage physique. Note : Wokwi simule le temps plus lentement que la réalité — ne pas l'utiliser pour valider les timings.

Un schéma de câblage Fritzing détaillé est fourni dans le dépôt (`fritzing/kegwasher.fzz` et `fritzing/kegwasher.png`). Il reflète la disposition physique réelle des composants dans le boîtier et met en évidence quatre zones : composants déportés (LCD, bouton action), bloc sécurité (arrêt d'urgence + contacteur), prises de puissance (résistance + pompe), zone hydraulique (électrovannes + bus bars). Le fichier source `.fzz` est inclus pour quiconque souhaite modifier ou étendre le schéma.

### Niveaux de compétence
- Les sections **accessibles aux débutants** sont marquées 🟢. Elles ne nécessitent aucune connaissance préalable en électronique — juste la capacité de suivre les instructions attentivement.
- Les sections **intermédiaires** sont marquées 🟡. Une familiarité de base avec le multimètre, le dénudage des fils et la lecture d'un schéma simple est utile.

### Outils nécessaires
- Pince à dénuder
- Tournevis plat et cruciforme
- Multimètre (tension et continuité)
- Outil à sertir (pour les embouts de câble, recommandé)
- Étiqueteuse ou étiquettes adhésives + marqueur

### Règles de sécurité — à lire avant de commencer
> ⚠️ **Le boîtier contient du 230 V CA secteur. Ne jamais intervenir sur le boîtier avec le câble d'alimentation branché.**

- Toujours débrancher la machine du secteur avant d'ouvrir le boîtier ou de toucher un câblage.
- La section 230 V (primaire de l'alimentation, entrée SSR, contacteur d'arrêt d'urgence) doit être câblée avec un câble de section appropriée (2,5 mm² minimum) et maintenue physiquement séparée de la section 12 V / 5 V.
- Utiliser des embouts de câble sur toutes les extrémités de fils souples insérés dans des borniers à vis. Les brins libres peuvent provoquer des courts-circuits.
- En cas de doute, mesurer avant de connecter. Un multimètre en mode continuité ne coûte rien et évite beaucoup de dégâts.

---

## Vue d'ensemble de l'architecture électrique

```
230 V CA secteur
     │
     ├──► Contacteur d'arrêt d'urgence (bouton coup-de-poing)
     │         │
     │         ▼
     │    Bus 230 V CA
     │         │
     │         ├──► Alimentation 12 V CC (120 W)
     │         │         │
     │         │         ├──► Bus 12 V ──► Carte de relais (bobines)
     │         │         │                 Électrovannes
     │         │         │                 Ventilateur SSR
     │         │         │
     │         │         └──► 5 V (depuis carte relais) ──► Arduino Uno
     │         │
     │         └──► SSR (40 A) ──► Thermoplongeur (2500 W)
     │                   ▲
     │              Thermostat STC1000 (signal de commande)
     │
     └──► Thermostat STC1000 (alimentation 230 V)
```

L'électronique de contrôle (Arduino, carte de relais, LCD, encodeur, boutons) fonctionne entièrement en **12 V / 5 V CC** et est complètement isolée de la section 230 V en fonctionnement normal. Les seuls composants 230 V à câbler sont l'alimentation, le SSR, le contacteur et le thermostat.

---

## Sous-système 1 — Préparation du boîtier 🟢

**Ce que c'est** : le boîtier plastique qui abrite toute l'électronique, monté sur le côté du châssis.

**Étapes** :
1. Planifier la disposition interne avant de percer. Disposition suggérée (de haut en bas, de l'avant vers l'arrière) :
   - Façade : LCD, encodeur rotatif, bouton action (LED), bouton d'arrêt d'urgence
   - Intérieur haut : Arduino + shield à bornier à vis, carte de relais
   - Intérieur bas : alimentation 12 V, SSR + radiateur + ventilateur
   - Entrées de câbles : bas du boîtier (éloigne l'humidité des composants)

2. Percer les découpes de la façade pour :
   - Fenêtre LCD (rectangulaire)
   - Axe de l'encodeur rotatif (rond, + méplat pour la vis de blocage du bouton)
   - Bouton action (rond)
   - Bouton d'arrêt d'urgence (rond, standard 22 mm)

3. Percer les entrées de câbles en bas du boîtier. Utiliser des presse-étoupes pour assurer le maintien mécanique et conserver l'indice de protection.

4. Monter les rails DIN ou les entretoises pour la fixation des composants si utilisés.

> 📷 *[Photo : découpes de la façade avant installation des composants]*
> 📷 *[Photo : vue d'ensemble de la disposition interne avec composants positionnés à blanc]*

---

## Sous-système 2 — Alimentation 12 V 🟡

**Ce que c'est** : une alimentation à découpage 230 VCA → 12 VCC (120 W). Elle alimente les bobines de la carte de relais, les électrovannes et le ventilateur du SSR. L'alimentation 5 V de l'Arduino est dérivée du régulateur intégré à la carte de relais.

**Étapes** :
1. Monter l'alimentation dans la partie basse du boîtier.
2. Connecter les bornes d'entrée 230 V CA (L, N, PE) avec un câble de 1,5 mm² depuis le bus de sortie du contacteur. **Ne pas connecter au secteur pour l'instant.**
3. Laisser les bornes de sortie 12 V CC (V+, V−) accessibles pour le sous-système suivant.
4. ✅ **Vérification** : avec un multimètre en tension CC, vérifier que la sortie est à 12 V ± 0,5 V avant de connecter toute charge.

> 📷 *[Photo : alimentation montée et câblée]*

---

## Sous-système 3 — Contacteur d'arrêt d'urgence 🟡

**Ce que c'est** : un contacteur (interrupteur électromécanique) dont la bobine est pilotée par le bouton coup-de-poing d'arrêt d'urgence. Appuyer sur le bouton désactive la bobine, ouvrant les contacts principaux et coupant tout le 230 V de la machine.

Utiliser un contacteur plutôt que de câbler le bouton directement dans la ligne 230 V signifie que le bouton ne commute qu'une bobine à faible courant (~VA), pas la charge totale de la machine. Cela améliore la sécurité et la longévité du bouton dans un environnement humide.

**Étapes** :
1. Monter le contacteur à l'intérieur du boîtier.
2. Connecter l'entrée secteur 230 V CA aux bornes d'entrée ligne du contacteur.
3. Connecter les bornes de sortie charge du contacteur au bus 230 V CA qui alimente l'alimentation et le SSR.
4. Câbler les bornes de bobine du contacteur au bouton d'arrêt d'urgence en façade. Quand le bouton est relâché (état normal), la bobine est alimentée et les contacts sont fermés. Appuyer sur le bouton coupe le circuit de la bobine, ouvrant les contacts.
5. Câbler le bouton d'arrêt d'urgence sur une source 230 V **en amont** du contacteur (le bouton doit rester alimenté même quand le contacteur est ouvert, pour pouvoir le réarmer).

> 📷 *[Photo : détail du câblage du contacteur]*
> 📷 *[Photo : bouton d'arrêt d'urgence en façade]*

> ⚠️ Vérifier la polarité et le marquage des bornes sur le modèle de contacteur utilisé. Les schémas de câblage varient selon les fabricants.

---

## Sous-système 4 — SSR et thermoplongeur 🟡

**Ce que c'est** : un relais statique (SSR) 40 A commute le thermoplongeur dans la cuve de détergent. Le SSR est piloté par le régulateur de température STC1000, qui surveille la température de la cuve via une sonde NTC en inox.

Un relais mécanique ne peut pas commuter fiablement une charge résistive de 2500 W sous 230 V. Le SSR supporte le courant de charge, tandis que la sortie du STC1000 (un relais à faible courant) pilote l'entrée de commande du SSR.

**Radiateur et ventilateur** *(amélioration Ecolab07)* : les SSR dissipent de la chaleur proportionnellement au courant de charge (environ 1–1,5 W par ampère). Sous pleine charge, un SSR 40 A peut dissiper 40–60 W sans radiateur — suffisant pour le détruire. Un radiateur et un ventilateur 12 V sont montés pour maintenir le SSR dans sa température de fonctionnement nominale pendant les longues sessions de chauffage.

**Note** : la résistance d'origine de 3500 W a été remplacée par **2500 W** pour éviter de déclencher le disjoncteur sur des circuits partagés. Le chauffage est plus lent mais reste dans la limite de courant permanent du disjoncteur.

**Étapes** :
1. Monter le SSR sur son radiateur avec de la pâte thermique. Fixer l'ensemble sur la paroi du boîtier (paroi métallique préférable pour la dissipation supplémentaire).
2. Monter le ventilateur 12 V de façon qu'il souffle sur les ailettes du radiateur. Connecter au bus 12 V — le ventilateur tourne en permanence quand la machine est sous tension.
3. Connecter les bornes de charge du SSR (côté CA) en série avec le câble d'alimentation du thermoplongeur (2,5 mm²).
4. Connecter les bornes de commande du SSR (côté CC, typiquement 3–32 V) aux bornes du relais de sortie du STC1000.
5. Câbler le STC1000 :
   - Alimentation 230 V sur l'entrée secteur du thermostat
   - Sonde de température sur l'entrée capteur du thermostat
   - Relais de sortie du thermostat sur l'entrée de commande du SSR (cf. ci-dessus)
6. Installer la sonde de température dans la cuve de détergent via son raccord 1/2" et son kit d'étanchéité.

> 📷 *[Photo : SSR monté sur radiateur avec ventilateur]*
> 📷 *[Photo : STC1000 câblé et monté]*

> ✅ **Vérification** : avec le thermoplongeur immergé et la machine sous tension, régler le STC1000 à une consigne au-dessus de la température ambiante. Vérifier que la LED du SSR s'allume quand le thermostat demande la chauffe, et que l'élément chauffant monte en température.

---

## Sous-système 5 — Carte de relais 🟡

**Ce que c'est** : une carte de relais 16 canaux (9 relais utilisés) qui commute l'alimentation 12 V vers chaque électrovanne et la pompe. Chaque relais est un interrupteur électromécanique avec une bobine 12 V pilotée par un signal logique de l'Arduino. La carte utilise une **logique active-low** : un signal LOW sur une pin de commande active le relais.

**Protection par diodes roue libre** : les électrovannes sont des charges inductives. À la désactivation d'une vanne, un bref pic de surtension (back-EMF) peut détruire les contacts des relais au fil du temps. Une diode roue libre 1N4148 placée aux bornes de chaque vanne (le plus près possible de la sortie du relais) écrête ce pic. **Ne pas omettre ces diodes** — le montage original Vieuxsinge a détruit plusieurs relais avant qu'elles ne soient ajoutées.

**Étapes** :
1. Monter la carte de relais à l'intérieur du boîtier, au-dessus de l'alimentation.
2. Connecter l'entrée d'alimentation 12 V de la carte au bus 12 V.
3. Connecter la sortie 5 V de la carte à la pin 5 V de l'Arduino (cela alimente l'Arduino).
4. Connecter le GND de la carte au GND de l'Arduino.
5. Connecter les pins numériques 2–10 de l'Arduino aux entrées de commande IN1–IN9 de la carte, selon le tableau de correspondance ci-dessous.
6. Pour chacune des 9 sorties de relais actives, câbler les bornes COM et NO (Normalement Ouvert) vers l'électrovanne ou la pompe correspondante, avec une diode roue libre 1N4148 aux bornes de la charge (cathode vers l'alimentation positive).

**Correspondance des pins** :

| Pin Arduino | Canal relais | Actionneur |
|---|---|---|
| 2 | IN1 | Électrovanne air |
| 3 | IN2 | Électrovanne CO₂ |
| 4 | IN3 | Électrovanne eau |
| 5 | IN4 | Vanne entrée détergent |
| 6 | IN5 | Vanne entrée désinfectant |
| 7 | IN6 | Vanne retour détergent |
| 8 | IN7 | Vanne retour désinfectant |
| 9 | IN8 | Vanne de vidange |
| 10 | IN9 | Pompe |

> 📷 *[Photo : carte de relais câblée, montrant les diodes roue libre sur les bornes de sortie]*

---

## Sous-système 6 — Bus bars en sortie des relais 🟢

**Ce que c'est** : des rampes de bus (bus bars) côté sortie des relais, qui regroupent le fil de retour 12 V commun pour des ensembles de vannes. *(Amélioration Ecolab07.)*

Sans bus bars, chaque vanne nécessite son propre fil de retour jusqu'à l'alimentation, produisant un faisceau dense de fils de couleur identique difficile à tracer et à entretenir. Les bus bars permettent un seul fil de retour commun par groupe, avec de courts cavaliers de chaque relais vers la rampe.

**Étapes** :
1. Monter une rampe de bus le long des bornes de sortie des relais.
2. Connecter une extrémité de la rampe au commun de l'alimentation 12 V (V−).
3. Pour chaque sortie de relais, passer un court fil de la borne NO du relais à la rampe (c'est le côté retour commun de la vanne).
4. Passer un fil dédié de la borne COM de chaque relais vers la borne positive de la vanne correspondante.
5. Placer une diode roue libre 1N4148 à chaque point de connexion de vanne (voir sous-système 5).

> 📷 *[Photo : bus bars avec câblage des vannes]*

---

## Sous-système 7 — Arduino et shield à bornier à vis 🟢

**Ce que c'est** : l'Arduino Uno est le cerveau de la machine. Un **shield à bornier à vis** empilé dessus (amélioration Ecolab07) remplace les fragiles connecteurs Dupont du design original par des borniers à vis robustes, et fournit une petite zone de prototypage pour la résistance de la LED.

**Étapes** :
1. Emboîter le shield à bornier à vis sur les connecteurs de l'Arduino Uno.
2. Sur la zone de prototypage du shield, souder une résistance de limitation de courant en série avec le fil signal de la LED (pin 11). Valeur typique : 220–470 Ω selon la tension de seuil de la LED et la luminosité souhaitée.
3. Monter l'ensemble Arduino + shield dans le boîtier avec des entretoises.
4. Connecter les pins de l'Arduino à la carte de relais (voir tableau sous-système 5).
5. Connecter les fils signal restants via les borniers :

| Pin Arduino | Connecté à |
|---|---|
| A0 | Borne positive du buzzer |
| A1 | Pin A de l'encodeur rotatif |
| A2 | Pin B de l'encodeur rotatif |
| A3 | Bouton action (avec pull-up via `INPUT_PULLUP` dans le firmware) |
| A4 | SDA du LCD |
| A5 | SCL du LCD |
| 11 | LED (via résistance sur la zone de prototypage) |

6. Connecter le 5 V et le GND de la carte de relais aux bornes correspondantes de l'Arduino.

> 📷 *[Photo : Arduino avec shield à bornier à vis, vue de dessus montrant la résistance sur la zone de prototypage]*
> 📷 *[Photo : Arduino monté dans le boîtier avec tous les fils connectés]*

---

## Sous-système 8 — Composants de façade 🟢

### Écran LCD
Le LCD est un afficheur I²C 16×2 avec un module backpack qui réduit la connexion à 4 fils : VCC (5 V), GND, SDA (A4), SCL (A5).

1. Monter le LCD derrière la découpe de la façade et fixer avec des vis ou de la colle chaude.
2. Connecter le câble I²C 4 fils au shield de l'Arduino.

> 📷 *[Photo : LCD monté en façade]*

### Encodeur rotatif
L'encodeur rotatif gère la sélection du mode (rotation).

1. Monter l'encodeur dans son trou de façade et fixer avec l'écrou.
2. Fixer le bouton sur l'axe.
3. Connecter les pins A et B de l'encodeur aux pins A1 et A2 de l'Arduino.
4. L'encodeur dispose d'un bouton-poussoir intégré — **note** : dans ce firmware, la fonction bouton utilise un bouton action dédié (voir ci-dessous), pas le bouton intégré à l'encodeur.

> 📷 *[Photo : encodeur rotatif avec bouton, vue façade]*

### Bouton action (avec LED)
Un bouton-poussoir momentané avec LED intégrée. La LED fournit le battement visuel pendant l'exécution des cycles.

1. Monter le bouton dans son trou de façade.
2. Connecter les bornes du bouton à A3 de l'Arduino et au GND. Le firmware utilise `INPUT_PULLUP`, donc aucune résistance de pull-up externe n'est nécessaire.
3. Connecter les bornes de la LED à la pin 11 de l'Arduino (via la résistance sur la zone de prototypage) et au GND.

> 📷 *[Photo : bouton action monté, vue arrière montrant le câblage]*

### Buzzer
Un buzzer piézo passif piloté par `tone()` sur la pin A0.

1. Monter ou coller le buzzer à l'intérieur du boîtier (pas besoin de découpe en façade — le son porte à travers les fentes de ventilation ou la paroi).
2. Connecter la borne positive à A0 de l'Arduino, la borne négative au GND.

---

## Sous-système 9 — Étiquetage des composants 🟢

*(Amélioration Ecolab07.)* Étiqueter chaque composant à l'intérieur du boîtier. Cela rend le diagnostic de pannes et les modifications futures accessibles sans avoir besoin de consulter ce guide.

Étiquettes suggérées :
- Canaux de relais : `RELAIS 1 — AIR`, `RELAIS 2 — CO2`, etc. (suivre le tableau de correspondance du sous-système 5)
- Sections des bus bars : `12V GND — VANNES`
- Bornes de l'alimentation : `12V OUT +`, `12V OUT −`
- SSR : `SSR — RESISTANCE`
- Borniers de l'Arduino : étiqueter chaque borne avec son nom de signal (AIR, CO2, EAU, etc.)

> 📷 *[Photo : intérieur du boîtier étiqueté, vue d'ensemble]*
> 📷 *[Photo : canaux de la carte de relais étiquetés]*

---

## Vérifications finales avant la première mise sous tension

Suivre cette checklist de haut en bas. Ne sauter aucune étape.

**Mécanique**
- [ ] Tous les borniers à vis sont serrés (tirer légèrement chaque fil)
- [ ] Aucun brin de fil nu visible hors des bornes
- [ ] Presse-étoupes serrés
- [ ] Le boîtier se ferme entièrement sans pincer de fils

**Section 230 V** *(multimètre en continuité, machine débranchée)*
- [ ] Pas de continuité entre L et N sur la fiche secteur
- [ ] Pas de continuité entre L/N et PE (terre) sur la fiche secteur
- [ ] Le bouton d'arrêt d'urgence ouvre le conducteur L quand on appuie dessus

**Section 12 V** *(machine sous tension, 230 V connecté, arrêt d'urgence relâché)*
- [ ] 12 V présents aux bornes de sortie de l'alimentation
- [ ] 12 V présents à l'entrée d'alimentation de la carte de relais
- [ ] 5 V présents à la pin 5 V de l'Arduino
- [ ] Toutes les LEDs des relais sont ÉTEINTES (logique active-low : tous les relais doivent être désactivés au démarrage)

**Téléversement du firmware**
- [ ] Connecter l'Arduino au PC via USB
- [ ] Ouvrir `kegwasher.ino` dans l'IDE Arduino
- [ ] Installer les librairies requises : `Bounce2`, `LiquidCrystal_I2C` (rechercher dans le gestionnaire de librairies), `RotaryEncoder`
- [ ] Sélectionner la carte : Arduino Uno, port COM correct
- [ ] Téléverser — aucune erreur de compilation
- [ ] Le LCD affiche `Mode :` et un nom de mode au démarrage
- [ ] L'encodeur rotatif fait défiler les modes
- [ ] Le bouton action lance un cycle

**Test des actionneurs** *(lancer avec toutes les cuves vides)*
- [ ] Sélectionner le mode `Test vannes`
- [ ] Confirmer le prompt `Cuves vides ?` à l'écran
- [ ] Chaque relais claque une fois dans l'ordre — vérifier à l'oreille ou au multimètre sur les bornes des vannes
- [ ] Tous les relais reviennent à l'état désactivé après le test

---

## Diagnostic des problèmes courants

| Symptôme | Cause probable | Action |
|---|---|---|
| Toutes les vannes s'ouvrent au démarrage | Pré-initialisation HIGH absente ou inefficace | Vérifier que le firmware a bien été téléversé ; vérifier la séquence de démarrage de l'Arduino |
| Une vanne ne s'ouvre jamais | Relais ne se déclenche pas, ou problème de câblage vanne | Tester la LED du relais lors de l'étape correspondante ; vérifier la tension aux bornes de la vanne |
| Une vanne ne se ferme jamais | Court-circuit de la diode roue libre | Retirer la diode et mesurer ; remplacer si en court-circuit |
| LCD vide / rétroéclairage seul | Mauvaise adresse I²C | Essayer `0x3F` à la place de `0x27` dans le firmware ; lancer un sketch de scan I²C |
| L'encodeur défile dans le mauvais sens | Pins A/B inversées | Inverser le câblage A1 et A2 |
| SSR en surchauffe | Refroidissement insuffisant | Vérifier que le ventilateur tourne ; vérifier le contact de la pâte thermique sur le radiateur |
| STC1000 ne chauffe pas | Signal de commande SSR absent | Mesurer la tension CC aux bornes de commande du SSR quand la chauffe est demandée |

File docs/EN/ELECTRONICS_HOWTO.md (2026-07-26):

# Electronics Assembly Guide — Keg Washer

> This project is a fork of [vieuxsinge/kegwasher](https://github.com/vieuxsinge/kegwasher)
> and [Gummy35/kegwasher](https://github.com/Gummy35/kegwasher).
> License: GNU GPL v3.

This guide walks through the assembly of the electronic control system, sub-system by sub-system, in the recommended build order. Component references and sourcing are covered in the separate [BOM](BOM.md).

> 📷 *Photo placeholders are marked throughout. Add your own images at the indicated locations.*

---

## Prerequisites

> 💡 **Before building**, you can test the complete circuit in the Wokwi simulator: [https://wokwi.com/projects/464738080652364801](https://wokwi.com/projects/464738080652364801). The simulation includes the Arduino, LCD, relay board, encoder, button, buzzer, and LEDs representing each solenoid valve. It is a useful way to familiarise yourself with the firmware behaviour before committing to physical wiring. Note that Wokwi simulates time slower than real speed — do not rely on it for timing validation.

A detailed Fritzing wiring diagram is provided in the repository (`fritzing/kegwasher.fzz` and `fritzing/kegwasher.png`). It reflects the actual physical layout of components inside the enclosure and highlights four zones: deported components (LCD, action button), safety block (emergency stop + contactor), power outlets (heater + pump), and hydraulic zone (solenoid valves + relay bus bars). The `.fzz` source file is included for anyone who wants to modify or extend the diagram.

### Skills
- **Beginner-friendly sections** are marked 🟢. They require no prior electronics knowledge — just the ability to follow instructions carefully.
- **Intermediate sections** are marked 🟡. Basic familiarity with multimeters, wire stripping, and reading a simple wiring diagram is helpful.

### Tools required
- Wire strippers
- Flat-head and Phillips screwdrivers
- Multimeter (voltage and continuity)
- Crimping tool (for ferrule end sleeves, recommended)
- Label maker or adhesive labels + marker

### Safety rules — read before you start
> ⚠️ **The enclosure contains 230 V AC mains voltage. Never work on the enclosure with the power cable connected.**

- Always disconnect the machine from the mains before opening the enclosure or touching any wiring.
- The 230 V section (transformer primary, SSR input, emergency stop contactor) must be wired with appropriately rated cable (2.5 mm² minimum) and kept physically separated from the 12 V / 5 V section.
- Use ferrule end sleeves on all stranded wire ends inserted into screw terminals. Loose strands can cause short circuits.
- When in doubt, measure before connecting. A multimeter in continuity mode costs nothing and prevents a lot of damage.

---

## Overview of the electrical architecture

```
230 V AC mains
     │
     ├──► Emergency stop contactor (mushroom-head button)
     │         │
     │         ▼
     │    230 V AC bus
     │         │
     │         ├──► 12 V DC power supply (120 W)
     │         │         │
     │         │         ├──► 12 V bus ──► Relay board (coils)
     │         │         │                 Solenoid valves
     │         │         │                 Cooling fan (SSR)
     │         │         │
     │         │         └──► 5 V (from relay board) ──► Arduino Uno
     │         │
     │         └──► SSR (40 A) ──► Immersion heater (3500 W)
     │                   ▲
     │              STC1000 thermostat (control signal)
     │
     └──► STC1000 thermostat (230 V supply)
```

The control electronics (Arduino, relay board, LCD, encoder, buttons) all operate at **12 V / 5 V DC** and are fully isolated from the 230 V section during normal operation. The only 230 V components that require wiring are the transformer primary, the SSR, the contactor, and the thermostat.

---

## Sub-system 1 — Enclosure preparation 🟢

**What it is**: the plastic enclosure that houses all electronics, mounted on the side of the frame.

**Steps**:
1. Plan the internal layout before drilling. Suggested arrangement (top to bottom, front to back):
   - Front panel: LCD, rotary encoder, action button (LED), emergency stop button
   - Upper interior: Arduino + terminal screw shield, relay board
   - Lower interior: 12 V power supply, SSR + heatsink + fan
   - Cable entry points: bottom of enclosure (keeps water ingress away from components)

2. Drill front panel cutouts for:
   - LCD window (rectangular)
   - Rotary encoder shaft (round, + flat for the knob grub screw)
   - Action button (round)
   - Emergency stop button (round, 22 mm standard)

3. Drill cable entry holes at the bottom of the enclosure. Use cable glands to provide strain relief and maintain IP rating.

4. Mount DIN rails or stand-offs for component fixings if used.

> 📷 *[Photo: front panel cutouts before component installation]*
> 📷 *[Photo: internal layout overview with components dry-fitted]*

---

## Sub-system 2 — 12 V power supply 🟡

**What it is**: a 230 VAC → 12 VDC switch-mode power supply (120 W rated). It powers the relay board coils, the solenoid valves, and the SSR cooling fan. The 5 V supply for the Arduino is derived from the relay board's onboard regulator.

**Steps**:
1. Mount the power supply in the lower section of the enclosure.
2. Connect the 230 V AC input terminals (L, N, PE) using 1.5 mm² cable from the contactor output bus. **Do not connect to mains yet.**
3. Leave the 12 V DC output terminals (V+, V−) accessible for the next sub-system.
4. ✅ **Check**: with a multimeter set to DC voltage, verify the output is 12 V ± 0.5 V before connecting any load.

> 📷 *[Photo: power supply mounted and wired]*

---

## Sub-system 3 — Emergency stop contactor 🟡

**What it is**: a contactor (electromechanical switch) whose coil is driven by the mushroom-head emergency stop button. Pressing the button de-energises the coil, opening the main power contacts and cutting all 230 V to the machine.

Using a contactor rather than wiring the button directly in the 230 V line means the button only switches a low-current coil (~VA), not the full machine load. This improves safety and button longevity in a damp environment.

**Steps**:
1. Mount the contactor inside the enclosure.
2. Connect the 230 V AC mains input to the contactor's line input terminals.
3. Connect the contactor's load output terminals to the 230 V AC bus that feeds the power supply and the SSR.
4. Wire the contactor coil terminals to the emergency stop button on the front panel. When the button is released (normal state), the coil is energised and the contacts are closed. Pressing the button breaks the coil circuit, dropping the contacts open.
5. Wire the emergency stop button to a 230 V source that is **upstream** of the contactor (the button must remain powered even when the contactor is open, in order to reset it).

> 📷 *[Photo: contactor wiring detail]*
> 📷 *[Photo: emergency stop button on front panel]*

> ⚠️ Double-check polarity and terminal labelling on your specific contactor model. Wiring diagrams vary between manufacturers.

---

## Sub-system 4 — SSR and immersion heater 🟡

**What it is**: a 40 A solid-state relay (SSR) switches the 3500 W immersion heater in the detergent tank. The SSR is controlled by the STC1000 temperature controller, which monitors the tank temperature via a stainless steel NTC probe.

A mechanical relay cannot reliably switch a 3500 W resistive load at 230 V. The SSR handles the load current, while the STC1000 output (a low-current relay) drives the SSR control input.

**Heatsink and cooling fan** *(Ecolab07 improvement)*: SSRs dissipate heat proportional to load current (approximately 1–1.5 W per amp). At full load, a 40 A SSR can dissipate 40–60 W without a heatsink — enough to destroy it. A heatsink and a 12 V fan are fitted to keep the SSR within its rated operating temperature during long heating sessions.

**Steps**:
1. Mount the SSR on its heatsink using thermal paste. Secure the assembly to the enclosure wall (metal wall preferred for additional heat spreading).
2. Mount the 12 V cooling fan so it blows air across the heatsink fins. Connect to the 12 V bus — the fan runs continuously when the machine is powered.
3. Connect the SSR load terminals (AC side) in series with the immersion heater supply cable (2.5 mm²).
4. Connect the SSR control terminals (DC side, typically 3–32 V) to the STC1000 output relay terminals.
5. Wire the STC1000:
   - 230 V supply to the thermostat's power input
   - Temperature probe to the thermostat's sensor input
   - Thermostat output relay to SSR control input (as above)
6. Install the temperature probe in the detergent tank via its 1/2" fitting and sealing kit.

> 📷 *[Photo: SSR mounted on heatsink with fan]*
> 📷 *[Photo: STC1000 wired and mounted]*

> ✅ **Check**: with the heater immersed and the machine powered, set the STC1000 to a target temperature above ambient. Verify the SSR LED lights when the thermostat calls for heat, and that the heater element warms up.

---

## Sub-system 5 — Relay board 🟡

**What it is**: a 16-channel relay board (only 9 relays are used) that switches the 12 V supply to each solenoid valve and the pump. Each relay is an electromechanical switch with a 12 V coil driven by a logic-level signal from the Arduino. The board uses **active-low logic**: a LOW signal on a control pin energises the relay.

**Flyback diode protection**: solenoid valves are inductive loads. When a valve de-energises, it produces a brief high-voltage back-EMF spike that can destroy relay contacts over time. A 1N4148 flyback diode placed across each valve terminal (as close to the relay output as possible) clamps this spike safely. **Do not omit these diodes** — the original Vieuxsinge build destroyed several relays before they were added.

**Steps**:
1. Mount the relay board inside the enclosure, above the power supply.
2. Connect the relay board's 12 V power input to the 12 V bus.
3. Connect the relay board's 5 V output to the Arduino's 5 V pin (this powers the Arduino).
4. Connect the relay board's GND to the Arduino GND.
5. Connect Arduino digital pins 2–10 to the relay board's IN1–IN9 control inputs, following the pin mapping table below.
6. For each of the 9 active relay outputs, wire the COM and NO (Normally Open) terminals to the corresponding solenoid valve or pump, with a 1N4148 flyback diode across the load terminals (cathode toward the positive supply).

**Pin mapping**:

| Arduino pin | Relay channel | Actuator |
|---|---|---|
| 2 | IN1 | Air solenoid valve |
| 3 | IN2 | CO₂ solenoid valve |
| 4 | IN3 | Water solenoid valve |
| 5 | IN4 | Detergent inlet valve |
| 6 | IN5 | Sanitizer inlet valve |
| 7 | IN6 | Detergent return valve |
| 8 | IN7 | Sanitizer return valve |
| 9 | IN8 | Drain valve |
| 10 | IN9 | Pump |

> 📷 *[Photo: relay board wired, showing flyback diodes on output terminals]*

---

## Sub-system 6 — Relay output bus bars 🟢

**What it is**: bus bar rails on the relay output side that group the common 12 V return wire for sets of valves. *(Ecolab07 improvement.)*

Without bus bars, each valve requires its own return wire all the way back to the power supply, producing a dense bundle of identically-coloured wires that is hard to trace and maintain. Bus bars allow one common return wire per group, with short jumpers from each relay to the bar.

**Steps**:
1. Mount a bus bar strip alongside the relay output terminals.
2. Connect one end of the bus bar to the 12 V supply common (V−).
3. For each relay output, run a short wire from the relay NO terminal to the bus bar (this is the common return side of the valve).
4. Run a dedicated wire from each relay COM terminal to the corresponding valve's positive terminal.
5. Place a 1N4148 flyback diode at each valve connection point (see Sub-system 5).

> 📷 *[Photo: bus bar rails with valve wiring]*

---

## Sub-system 7 — Arduino and terminal screw shield 🟢

**What it is**: the Arduino Uno is the brain of the machine. A **terminal screw shield** stacked on top of it (Ecolab07 improvement) replaces the fragile Dupont pin connectors of the original design with robust screw terminals, and provides a small prototyping area for the LED resistor.

**Steps**:
1. Stack the terminal screw shield onto the Arduino Uno headers.
2. On the prototyping area of the shield, solder a current-limiting resistor in series with the LED signal wire (pin 11). Typical value: 220–470 Ω depending on your LED's forward voltage and desired brightness.
3. Mount the Arduino + shield assembly inside the enclosure using stand-offs.
4. Connect Arduino pins to the relay board (see Sub-system 5 pin mapping).
5. Connect the remaining signal wires using the terminal blocks:

| Arduino pin | Connected to |
|---|---|
| A0 | Buzzer positive terminal |
| A1 | Rotary encoder pin A |
| A2 | Rotary encoder pin B |
| A3 | Action button (with pull-up via `INPUT_PULLUP` in firmware) |
| A4 | LCD SDA |
| A5 | LCD SCL |
| 11 | LED (via resistor on prototyping area) |

6. Connect 5 V and GND from the relay board to the corresponding Arduino terminals.

> 📷 *[Photo: Arduino with terminal screw shield, top view showing resistor on prototyping area]*
> 📷 *[Photo: Arduino mounted in enclosure with all wires connected]*

---

## Sub-system 8 — Front panel components 🟢

### LCD screen
The LCD is an I²C 16×2 display with a backpack module that reduces the connection to 4 wires: VCC (5 V), GND, SDA (A4), SCL (A5).

1. Mount the LCD behind the front panel cutout and secure with screws or hot glue.
2. Connect the 4-wire I²C cable to the Arduino terminal shield.

> 📷 *[Photo: LCD mounted on front panel]*

### Rotary encoder
The rotary encoder handles both mode selection (rotation) and confirmation (push).

1. Mount the encoder through its front panel hole and secure with the nut.
2. Fit the knob onto the shaft.
3. Connect encoder pins A and B to Arduino A1 and A2.
4. Connect the encoder's built-in push-button to a separate Arduino pin if used — **note**: in this firmware, the push-button function uses a dedicated action button (see below), not the encoder's built-in switch.

> 📷 *[Photo: rotary encoder with knob, front panel view]*

### Action button (with LED)
A momentary push-button with an integrated LED. The LED provides the visual heartbeat during cycle operation.

1. Mount the button through its front panel hole.
2. Connect the button terminals to Arduino A3 and GND. The firmware uses `INPUT_PULLUP`, so no external pull-up resistor is needed.
3. Connect the LED terminals to Arduino pin 11 (via the resistor on the prototyping area) and GND.

> 📷 *[Photo: action button mounted, rear view showing wiring]*

### Buzzer
A passive piezo buzzer driven by `tone()` on pin A0.

1. Mount or affix the buzzer inside the enclosure (it does not need a front panel cutout — the sound carries through the enclosure vents or wall).
2. Connect positive terminal to Arduino A0, negative terminal to GND.

---

## Sub-system 9 — Component labelling 🟢

*(Ecolab07 improvement.)* Label every component inside the enclosure. This makes fault-finding and future modifications accessible without needing to refer to this guide.

Suggested labels:
- Relay channels: `RELAY 1 — AIR`, `RELAY 2 — CO2`, etc. (follow the pin mapping table in Sub-system 5)
- Bus bar sections: `12V GND — VALVES`
- Power supply terminals: `12V OUT +`, `12V OUT −`
- SSR: `SSR — HEATER`
- Arduino terminal blocks: label each terminal with its signal name (AIR, CO2, WATER, etc.)

> 📷 *[Photo: labelled enclosure interior, full view]*
> 📷 *[Photo: labelled relay board channels]*

---

## Final checks before first power-up

Work through this checklist top to bottom. Do not skip steps.

**Mechanical**
- [ ] All screw terminals are tight (tug each wire gently)
- [ ] No bare wire strands visible outside terminals
- [ ] Cable glands are tightened
- [ ] Enclosure closes fully with no wires pinched

**230 V section** *(multimeter set to continuity, machine unplugged)*
- [ ] No continuity between L and N at the mains plug
- [ ] No continuity between L/N and PE (earth) at the mains plug
- [ ] Emergency stop button opens the L conductor when pressed

**12 V section** *(machine powered, 230 V connected, emergency stop released)*
- [ ] 12 V present at power supply output terminals
- [ ] 12 V present at relay board power input
- [ ] 5 V present at Arduino 5 V pin
- [ ] All relay LEDs are OFF (active-low: all relays should be de-energised at boot)

**Firmware upload**
- [ ] Connect Arduino to PC via USB
- [ ] Open `kegwasher.ino` in Arduino IDE
- [ ] Install required libraries: `Bounce2`, `LiquidCrystal_I2C` (fdebrabander fork), `RotaryEncoder`
- [ ] Select board: Arduino Uno, correct COM port
- [ ] Upload — no compilation errors
- [ ] LCD displays `Mode :` and a mode name on boot
- [ ] Rotary encoder scrolls through modes
- [ ] Action button launches a cycle

**Actuator test** *(run with all tanks empty)*
- [ ] Select `Test vannes` mode
- [ ] Confirm `Cuves vides ?` prompt on screen
- [ ] Each relay clicks once in sequence — verify by ear or multimeter on valve terminals
- [ ] All relays return to de-energised state after the test

---

## Troubleshooting

| Symptom | Likely cause | Check |
|---|---|---|
| All valves open at power-up | Pre-drive HIGH missing or ineffective | Verify firmware was uploaded correctly; check Arduino boot sequence |
| One valve never opens | Relay not triggering, or valve wiring | Test relay LED when that step runs; check valve terminal voltage |
| One valve never closes | Flyback diode short circuit | Remove diode and measure; replace if shorted |
| LCD blank / backlight only | Wrong I²C address | Try `0x3F` instead of `0x27` in firmware; run an I²C scanner sketch |
| Encoder scrolls in wrong direction | A/B pins swapped | Swap A1 and A2 wiring |
| SSR overheating | Insufficient cooling | Check fan is running; verify heatsink thermal paste contact |
| STC1000 not heating | SSR control signal absent | Measure DC voltage across SSR control terminals when heating is demanded |

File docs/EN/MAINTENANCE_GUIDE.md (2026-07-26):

# Maintenance Guide — Keg Washer

> This project is a fork of [vieuxsinge/kegwasher](https://github.com/vieuxsinge/kegwasher)
> and [Gummy35/kegwasher](https://github.com/Gummy35/kegwasher).
> License: GNU GPL v3.

---

## Table of Contents

1. [Safety reminders](#1-safety-reminders)
2. [Maintenance schedule overview](#2-maintenance-schedule-overview)
3. [After each session](#3-after-each-session)
4. [Weekly](#4-weekly)
5. [Monthly](#5-monthly)
6. [Seasonally / end of season](#6-seasonally--end-of-season)
7. [As needed](#7-as-needed)
8. [Troubleshooting common issues](#8-troubleshooting-common-issues)

---

## 1. Safety reminders

> ⚠️ **Always disconnect the machine from the mains before opening the enclosure or touching any internal component.**

- Never perform maintenance on the hydraulic circuit while a cycle is running.
- After an emergency stop, verify that all valves have returned to their closed (rest) state before inspecting the circuit.
- Wear appropriate PPE (gloves, eye protection) when handling detergent (caustic soda) or sanitizer (peracetic acid) solutions.
- Rinse any skin contact with running water immediately.

---

## 2. Maintenance schedule overview

| Task | After each session | Weekly | Monthly | Seasonal |
|---|---|---|---|---|
| Rinse wash heads | ✅ | | | |
| Check product tank levels | ✅ | | | |
| Check hose connections for leaks | ✅ | | | |
| Inspect wash heads for scale/fouling | | ✅ | | |
| Check solenoid valve response (listen for click) | | ✅ | | |
| Verify STC1000 temperature reading | | ✅ | | |
| Inspect flyback diodes and relay board | | | ✅ | |
| Check all screw terminal tightness | | | ✅ | |
| Full drain and renew product solutions | | | | ✅ |
| Descale hydraulic circuit | | | | ✅ |
| Inspect pump seals and impeller | | | | ✅ |
| Inspect hoses for cracks or hardening | | | | ✅ |
| Run `Test vannes` actuator test | | | ✅ | |
| Clean enclosure interior | | | | ✅ |

---

## 3. After each session

### 3.1 Rinse wash heads 🟢
After removing the kegs, flush the wash heads with clean water to remove residual product. Dry with a clean cloth and store in a clean location.

### 3.2 Check product tank levels 🟢
Visually check the detergent and sanitizer tank levels. Top up if needed before the next session so the machine is ready to use.

> Note: detergent solution (caustic soda) concentration degrades over time with use. Track the number of wash cycles between renewals and follow your product supplier's recommendations.

### 3.3 Check hose connections 🟢
Walk around the machine and visually inspect all hose connections for drips or weeping. Tighten any loose hose clamps. A small leak left unattended can corrode fittings and stainless steel surfaces over time.

---

## 4. Weekly

### 4.1 Inspect wash heads for scale and fouling 🟢
Hard water deposits (limescale) and peracetic acid residue can build up inside the wash head nozzles, reducing flow and cleaning effectiveness.

- Disassemble the wash heads if your model allows it.
- Soak in a dilute descaling solution (citric acid or proprietary descaler) for 30 minutes.
- Rinse thoroughly before reinstalling.

### 4.2 Check solenoid valve response 🟢
Run the `Test vannes` mode (all tanks empty) and listen for each relay click and valve actuation in sequence. A valve that does not click or does not produce a flow change when expected may be sticking or have a failed coil.

### 4.3 Verify STC1000 temperature reading 🟢
Check that the STC1000 display reads a plausible temperature for the detergent tank (ambient if cold, target temperature if recently heated). An implausible reading (e.g. `---` or a value far outside range) indicates a failed or disconnected temperature probe.

---

## 5. Monthly

### 5.1 Inspect flyback diodes and relay board 🟡
Open the enclosure (machine unplugged). Visually inspect:
- The 1N4148 flyback diodes at each relay output — look for any that are visibly burnt, cracked, or have discoloured surrounding wiring.
- The relay board itself — look for burnt or discoloured relay bodies, which indicate a relay that has been running near its current limit.
- All Dupont connectors or terminal block connections between the Arduino and relay board — re-seat any that feel loose.

### 5.2 Check all screw terminal tightness 🟡
With the machine unplugged, use a flat-head screwdriver to gently re-tighten every screw terminal in the enclosure. Thermal cycling (heating and cooling) causes terminals to loosen over time, which can cause intermittent faults or arcing.

Pay particular attention to:
- The 230 V section (transformer primary, SSR, contactor)
- The relay output terminals connected to solenoid valve cables

### 5.3 Run the actuator test 🟢
Run `Test vannes` with all tanks empty. This provides a monthly baseline: if a relay that previously clicked cleanly now sounds different or fails to actuate its valve, investigate before the issue becomes a cycle failure mid-wash.

---

## 6. Seasonally / end of season

### 6.1 Full drain and renew product solutions 🟢
At the end of the brewing season (or when solutions have been in use for the recommended duration):

1. Run `Vidange deter.` to pump out the detergent tank through the circuit.
2. Run `Vidange desinf.` to pump out the sanitizer tank.
3. Use `Rempl. deter.` and `Rempl. desinf.` to refill with fresh water.
4. Run a full wash cycle (`Lavage sans CO2`) with plain water to rinse all lines.
5. Drain again with `Vidange deter.` and `Vidange desinf.`.
6. Prepare and add fresh product solutions at the correct concentrations:
   - Detergent: caustic soda 2 % (by weight)
   - Sanitizer: peracetic acid 1 % (follow product datasheet)

> ⚠️ Always add chemical concentrates to water, not water to concentrate. Wear gloves and eye protection.

### 6.2 Descale the hydraulic circuit 🟡
Hard water scale builds up progressively inside hoses, fittings, the pump, and valve bodies. A seasonal descaling prevents blockages and maintains flow rates.

1. Fill the detergent tank with a dilute citric acid solution (1–2 % by weight) at room temperature.
2. Run `Lavage sans CO2` to circulate the descaling solution through the full circuit.
3. Drain with `Vidange deter.`.
4. Run two plain-water rinse cycles to flush residual acid before refilling with detergent solution.

> Note: do not use citric acid at high temperature — it accelerates corrosion of stainless steel fittings.

### 6.3 Inspect pump seals and impeller 🟡
The Novax 20B pump (or equivalent) has rubber seals that degrade with chemical exposure over time.

- Inspect the pump head for any weeping around the shaft seal.
- If the pump has been noisy or showing reduced flow, open the pump head and inspect the impeller for wear, cracking, or chemical damage.
- Replace seals annually or at the first sign of leakage.

### 6.4 Inspect hoses 🟢
Inspect all hoses for:
- Cracks, kinks, or hardening (especially Thermoclean hose near heat sources)
- Soft spots or bulges (indicating internal delamination)
- Discolouration or chemical degradation at fittings

Replace any suspect section before the start of the next season. Hose failure mid-cycle can cause chemical spills and machine damage.

### 6.5 Clean the enclosure interior 🟡
With the machine unplugged:
- Use a dry cloth or soft brush to remove dust from the relay board, Arduino, and terminal blocks.
- Do not use compressed air directly on the relay board — it can drive conductive dust into relay contacts.
- Wipe the interior walls of the enclosure with a slightly damp cloth, then dry thoroughly before closing.
- Check that the SSR heatsink and cooling fan are free of dust buildup. A clogged heatsink significantly reduces thermal performance.

---

## 7. As needed

### 7.1 Replace a solenoid valve 🟡
Signs of a failing solenoid valve: valve does not open (no flow despite relay clicking), valve does not close (constant drip at rest), or coil overheating.

1. Run `Vidange deter.` and `Vidange desinf.` to empty the lines.
2. Shut off the water supply.
3. Depressurise the circuit by running a short `Vidange fut` cycle.
4. Disconnect the valve's electrical connector at the relay output terminal.
5. Unscrew the valve from its fitting (PTFE tape seal will need replacing).
6. Install the new valve with fresh PTFE tape. Tighten to the fitting manufacturer's torque specification.
7. Reconnect the electrical terminals. Ensure the flyback diode is in place.
8. Run `Test vannes` to verify the replacement valve responds correctly before refilling the tanks.

### 7.2 Replace a relay 🟡
Signs of a failing relay: relay does not click when signalled, relay clicks but load voltage is absent, relay contacts welded (valve stays open when it should close).

1. Unplug the machine.
2. Identify the failed relay channel from the board labelling.
3. Disconnect the wiring from the relay output terminals.
4. Most relay boards use socketed relays — pull the relay body straight out of its socket and press the replacement in.
5. Reconnect wiring. Verify flyback diode is in place on the output.
6. Power up and run `Test vannes` to confirm.

### 7.3 Replace the SSR cooling fan 🟢
If the fan stops running (audible silence, or visible from enclosure vents):

1. Unplug the machine.
2. Disconnect the fan's 12 V power wires.
3. Unscrew and replace with an equivalent 12 V fan of the same dimensions.
4. Reconnect and verify rotation direction — airflow should blow across the heatsink fins, not away from them.

### 7.4 Adjust wash cycle timing 🟢
Step durations are defined directly in the `step_t` arrays in `kegwasher.ino`. To adjust a step duration:

1. Open `kegwasher.ino` in the Arduino IDE.
2. Find the relevant step array (e.g. `STEPS_WASH_KEG_PRESSURIZE`).
3. Change the duration value (in seconds) for the relevant step.
4. Re-upload the firmware to the Arduino.

Steps marked `// Adjust if needed` in the source code are the most likely candidates for tuning to your specific water pressure, pump, and product concentrations.

---

## 8. Troubleshooting common issues

| Symptom | Likely cause | Action |
|---|---|---|
| Detergent tank not reaching 80 °C | SSR not switching / probe fault / heater fault | Check STC1000 display; measure SSR control voltage; check heater continuity |
| Poor cleaning results | Detergent concentration low / temperature too low / step durations too short | Check concentration; verify STC1000 setpoint; increase step durations in firmware |
| Residual product smell after rinse | Rinse steps too short | Increase `CONFIG_RINCE` durations in `STEPS_WASH_KEG*` arrays |
| Pump noisy or low flow | Air in circuit / impeller wear / inlet restriction | Check inlet valve is opening; inspect pump head |
| Valve stays open after cycle | Relay contacts welded or debris in valve seat | Run `Test vannes`; replace relay or clean/replace valve |
| Valve never opens | Coil failure / relay failure / wiring fault | Check relay click; measure voltage at valve terminals |
| LCD shows wrong temperature on STC1000 | Probe disconnected or failed | Check probe connector; replace probe if reading is implausible |
| Machine trips RCD/GFCI | Earth leakage in heater or pump | Disconnect loads one by one to isolate; check heater element insulation resistance |

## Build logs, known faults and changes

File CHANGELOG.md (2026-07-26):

# Changelog

All notable changes to this project are documented in this file.

This project follows a fork lineage:
- **v1.x** — [vieuxsinge/kegwasher](https://github.com/vieuxsinge/kegwasher) (original project)
- **v2.x** — [Gummy35/kegwasher](https://github.com/Gummy35/kegwasher) (first fork)
- **v3.x** — [ecolab07/kegwasher](https://github.com/ecolab07/kegwasher) (this fork)

---

## [3.x] — ecolab07 fork

### Added
- **Actuator test mode** (`Test vannes` / `STEPS_TEST_ACTUATORS`): fires each of the 9 actuators individually for 1 second in relay-board order, with a safety prompt (`CONFIG_WARNING`) before the first pulse and a 1 s idle gap (`CONFIG_WAIT`) between each actuation. Implemented entirely as a `step_t` array — no changes to the control layer. Two pseudo-configuration flags introduced: `CONFIG_WARNING` (bit 10) and `CONFIG_WAIT` (bit 11), both outside the 9-bit actuator range so no physical output is triggered.
- **Pin pre-initialisation to HIGH**: all relay control pins are driven HIGH before `pinMode(OUTPUT)` is called in `setup()`, preventing the brief LOW glitch that would otherwise energise all relays at power-up and cause an inrush current spike.
- **`resolve_label()`**: pure function returning a `const char*` label for any valve configuration, replacing the former `config_label` global variable. Used by `run_update()` for the alternating LCD display.
- **`close_actuators()` / `open_actuators()`**: `controls_set_state()` split into two dedicated functions, one per direction, each with its own fixed actuator order. Removes the direction-switching `if/else` and makes the sequencing intent explicit.
- **Minimal transition logic in `controls_set()`**: transitions now only touch actuators that actually change state, using bitmask arithmetic:
  ```c
  unsigned int to_close = previous_config & ~config;
  unsigned int to_open  = config & ~previous_config;
  ```
  `previous_config` is tracked globally and reset to 0 at each mode start. This eliminates unnecessary relay switching, reduces inrush current, and makes `CONFIG_WARNING` / `CONFIG_WAIT` safe by design (their bits above bit 9 produce zero when AND-masked against the 9-bit actuator range).

### Changed
- **Rotary encoder negative value guard** — corrected formula:
  - v3.0 (initial): `(pos + MODES_NUMBER) % MODES_NUMBER` — silently fails when `pos` is more negative than `-MODES_NUMBER` (C modulo sign follows dividend)
  - v3.1 (current): `((pos % MODES_NUMBER) + MODES_NUMBER) % MODES_NUMBER` — always produces a result in `[0, MODES_NUMBER-1]` regardless of how far counter-clockwise the encoder has been turned
- **Type safety**: `step_t.duration`, all time variables (`mode_start_time`, `mode_full_time`, `step_start_time`) and `seconds()` return type changed from `int` to `unsigned long`, consistent with `millis()` and correct for AVR where `int` is 16 bits (max 32 767 s ≈ 9 h).
- **`MODES_NUMBER`**: changed from mutable `int` to `const int`.
- **`lcd_printf`**: removed spurious `sizeof-1` (vsnprintf already guarantees null termination within the provided buffer size).
- **`step_start_time` recorded after transitions**: in `step_set()`, the step chrono now starts after `controls_set()` returns, so each step's declared duration is measured from when the valves are actually in their target state.
- **`mode_start_time` recorded after `step_set(0)`**: same rationale — the mode chrono excludes the transition overhead of the first step.
- **`CONFIG_FILL_SANITIZER` / `CONFIG_FILL_CLEANER`**: pump (`CTRL_PUMP`) restored and inlet valves corrected. Gummy35 had removed the pump (filling by mains pressure only). In practice, water enters via the keg and must be pumped back into the tank through the return valves (`CTRL_SANITIZER_OUT` / `CTRL_CLEANER_OUT`) — the inlet valves (`*_IN`) are oriented in the wrong direction for this flow path.
- **Immersion heater downrated from 3500 W to 2500 W**: the 3500 W element was tripping the circuit breaker on shared circuits. The 2500 W element heats more slowly but stays within the breaker's sustained current rating.

### Known limitation — displayed time vs real time
The 200 ms inter-actuator delay in `close_actuators()` and `open_actuators()` is blocking: it consumes wall-clock time during which `loop()` does not run. As a result, displayed seconds are slightly longer than real seconds — each transition between steps adds a small overhead proportional to the number of actuators that change state. This is addressed in branch `feature/nonblocking-timers` (see below).

### In progress
- **`feature/nonblocking-timers`**: `step_start_time` and `mode_start_time` use `millis()` for ms-precision step expiry; a `transition_overhead` accumulator subtracts blocking transition time from the displayed elapsed time so the LCD always shows real hydraulic time.
- **`feature/rotary-interrupts`**: rotary encoder and button handling migrated to Pin Change Interrupts (PCINT), eliminating the need to call `menuselect.tick()` and `buttonAction.update()` in the main loop.
- Terminal screw shield on the Arduino with integrated prototyping area, used to mount the LED current-limiting resistor and provide robust screw-terminal connections in place of Dupont connectors.
- Emergency stop button now drives a **contactor** rather than being wired directly in the load circuit, improving safety and button longevity.
- SSR fitted with a **heatsink and 12 V cooling fan** to prevent thermal runaway during long detergent heating sessions.
- **Bus bar rails** on relay outputs to simplify solenoid valve wiring and improve enclosure readability.
- All components inside the enclosure identified with **adhesive labels**.

### Documentation
- Full bilingual documentation added (English + French): user manual, technical README, electronics assembly guide, maintenance guide, CHANGELOG, CONTRIBUTING.

---

## [2.x] — Gummy35 fork

### Added
- **Ordered actuator open/close sequencing** (`controls_set_state()` refactored from scratch): actuators are now opened and closed one at a time in a defined order with a configurable inter-actuator delay. Closing order: pump → water/CO₂/air → liquid inlets → return paths → drain. Opening order: drain/returns → liquid inlets → pump → air → CO₂ → water. Prevents pressure spikes, back-flow into gas lines, and relay inrush current spikes. Closing delay increased from 0 ms to 200 ms.
- **LCD alternating display**: `config_label` string resolved inside `controls_set_state()` via a `switch` on the active configuration; line 1 alternates between the current step label and the mode name in sync with the LED blink cadence.
- **New wash modes**:
  - `Detergent seul` (`STEPS_DETER_KEG`): detergent wash and rinses only, no sanitization.
  - `CO2` (`STEPS_KEG_PRESSURIZE`): CO₂ purge and pressurisation only.
  - `Desinf. + CO2` (`STEPS_SANITIZE_KEG_PRESSURIZE`): sanitization cycle followed by CO₂ pressurisation.
- **CO₂ pressurisation step** (`{CONFIG_CO2, 10}`) added to `STEPS_WASH_KEG_PRESSURIZE`.
- **`CONFIG_CO2` define** added (was missing from the original).
- **`VALVE_OPEN` / `VALVE_CLOSE` defines** replacing raw `HIGH`/`LOW` in control calls, making active-low relay logic explicit.
- **`CONFIG_FILL_SANITIZER/CLEANER`**: pump removed from the fill configurations (filling by mains pressure only, no pump).
- A fully commented-out `STEPS_WASH_KEG_PRESSURIZE_SAFE` variant that drains sanitizer to the waste outlet rather than returning it to the tank — left as a reference for future exploration.

### Changed — timing overhaul
Gummy35 significantly increased step durations across all wash cycles as a safety margin, with more intermediate passes at each phase. Key changes to `STEPS_WASH_KEG` and `STEPS_WASH_KEG_PRESSURIZE`:

| Phase | Vieuxsinge | Gummy35 |
|---|---|---|
| Initial drain | 10 s | 25 s |
| Initial rinse | 30 s (2 passes) | 103 s (4 passes) |
| Detergent | 75 s (3×10 s + purges) | 203 s (8 passes + purges) |
| Intermediate rinse | 60 s (3 passes) | 90 s (4 passes) |
| Sanitization | 65 s (3×10 s + purges) | 113 s (5 passes + purges) |
| Final purge | CO₂ 30 s | Air 30 s (no CO₂ in `STEPS_WASH_KEG`) |
| **Total** | **325 s (5 min 25)** | **579 s (9 min 39)** |

> ⚠️ **Note (ecolab07 fork)**: the timing increases introduced by Gummy35 were considered overly conservative for the reference installation. This fork restores the original Vieuxsinge timings for all pre-existing modes. The three new modes are kept with timings aligned to the Vieuxsinge baseline. If your installation requires longer cycles (lower water pressure, larger tank volume, different chemical concentrations), adjust step durations locally — see [CONTRIBUTING.md](CONTRIBUTING.md) §7.

---

## [1.x] — vieuxsinge original

### Foundation
- Arduino Uno-based control system for a 2-head keg washer.
- Step-based sequence engine: wash programs defined as `step_t` arrays terminated by `{CONFIG_END, 0}`.
- 9-bit actuator bitmask model (`CTRL_*` defines) with composite `CONFIG_*` configurations.
- Wash modes: `Lavage + CO2`, `Lavage sans CO2`, `Vidange fut`, `Vidange desinf.`, `Vidange deter.`, `Rempl. desinf.`, `Rempl. deter.`.
- Rotary encoder menu with EEPROM persistence of last selected mode.
- I²C LCD display, buzzer end-of-cycle notification, LED heartbeat.
- State machine: `STATE_SELECT` → `STATE_RUN` → `STATE_TERMINATE` / `STATE_CANCEL`.

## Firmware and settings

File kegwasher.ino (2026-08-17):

// ============================================================
// kegwasher — sketch de production, réparti en plusieurs onglets .ino
//
// Cet onglet (qui porte le nom du dossier) est TOUJOURS concaténé en
// premier par l'IDE Arduino, avant tous les autres. C'est pour ça qu'il
// porte tout ce qui doit être visible ailleurs avant d'être utilisé :
// les #define, les typedef, les objets matériels et les variables d'état
// globales. Les autres onglets ne contiennent que des fonctions (l'IDE
// génère leurs prototypes automatiquement, donc leur ordre entre eux n'a
// pas d'importance) — mais ils ne doivent JAMAIS définir une variable
// globale ou un type dont cet onglet-ci (ou un onglet concaténé avant eux)
// aurait besoin.
//
// Ordre de concaténation réel :
//   kegwasher.ino (ce fichier)
//   a_donnees_modes.ino   — tableaux STEPS_*[], MODES[], read_step()
//   b_affichage.ino       — lcd_printf(), resolve_label()
//   c_actionneurs.ino     — pilotage des vannes, step_set()
//   d_cycle.ino           — select/run/terminate/cancel (le cœur du cycle)
//   e_reprise.ino         — détection de coupure, écran d'alerte au boot
// ============================================================

#include <stdarg.h>
#include <EEPROM.h>
#include <Bounce2.h>
#include <Wire.h>
#include <LiquidCrystal_I2C.h>
#include <RotaryEncoder.h>

// ============================================================
// Pin assignments
// ============================================================
#define PIN_BUZZER                A0
#define PIN_MENUSELECT_1          A1  // Rotary encoder A
#define PIN_MENUSELECT_2          A2  // Rotary encoder B
#define PIN_BUTTON_ACTION         A3  // Confirm / cancel button
#define PIN_VALVE_AIR             2
#define PIN_VALVE_CO2             3
#define PIN_VALVE_WATER           4
#define PIN_VALVE_CLEANER_IN      5
#define PIN_VALVE_SANITIZER_IN    6
#define PIN_VALVE_CLEANER_OUT     7
#define PIN_VALVE_SANITIZER_OUT   8
#define PIN_VALVE_DRAIN           9
#define PIN_PUMP                  10
#define PIN_LED                   11

#define DISPLAY_I2C_ADDRESS       0x27

// ============================================================
// Individual actuator control bits (9 bits, one per output)
// ============================================================
#define CTRL_WATER          0b000000001
// Tank outlet = circuit inlet (liquid drawn from cleaner tank)
#define CTRL_CLEANER_IN     0b000000010
// Tank outlet = circuit inlet (liquid drawn from sanitizer tank)
#define CTRL_SANITIZER_IN   0b000000100
#define CTRL_AIR            0b000001000
#define CTRL_CO2            0b000010000
#define CTRL_DRAIN          0b000100000
// Tank upper inlet = circuit outlet (liquid returns to cleaner tank)
#define CTRL_CLEANER_OUT    0b001000000
// Tank upper inlet = circuit outlet (liquid returns to sanitizer tank)
#define CTRL_SANITIZER_OUT  0b010000000
#define CTRL_PUMP           0b100000000

// Extended flags used by the "Test vannes" mode only (bits 10 and 11,
// outside the range of real actuator bits)
#define CONFIG_WARNING  0b1000000000   // Prompt operator before firing any actuator (bit 10)
#define CONFIG_WAIT     0b10000000000  // Idle gap between individual actuator pulses (bit 11)

// ============================================================
// Composite valve configurations used by normal wash sequences
// ============================================================
#define CONFIG_DRAIN            (CTRL_DRAIN)
#define CONFIG_DRAIN_SANITIZER  (CTRL_PUMP + CTRL_SANITIZER_IN + CTRL_DRAIN)
#define CONFIG_DRAIN_CLEANER    (CTRL_PUMP + CTRL_CLEANER_IN + CTRL_DRAIN)
#define CONFIG_FILL_SANITIZER   (CTRL_PUMP + CTRL_SANITIZER_OUT + CTRL_WATER)
#define CONFIG_FILL_CLEANER     (CTRL_PUMP + CTRL_CLEANER_OUT + CTRL_WATER)
#define CONFIG_RINCE            (CTRL_PUMP + CTRL_WATER + CTRL_DRAIN)
#define CONFIG_RINCE_PURGE      (CTRL_AIR + CTRL_DRAIN)
#define CONFIG_RINCE_PURGE_CO2  (CTRL_CO2 + CTRL_DRAIN)
#define CONFIG_CLEAN            (CTRL_PUMP + CTRL_CLEANER_IN + CTRL_CLEANER_OUT)
#define CONFIG_CLEAN_PURGE      (CTRL_AIR + CTRL_CLEANER_OUT)
#define CONFIG_SANITIZE         (CTRL_PUMP + CTRL_SANITIZER_IN + CTRL_SANITIZER_OUT)
#define CONFIG_SANITIZE_PURGE   (CTRL_AIR + CTRL_SANITIZER_OUT)
#define CONFIG_CO2              (CTRL_CO2)
#define CONFIG_END              0  // Sentinel value marking the end of a step array

// LED blink period in seconds during a running sequence
#define LED_BLINK_PERIOD    2

// Relay logic: relays are active-low
#define VALVE_CLOSE HIGH
#define VALVE_OPEN  LOW

// Custom LCD character index: up/down arrows used in the selection screen
#define CHAR_UP_DOWN  1

// ============================================================
// EEPROM addresses
// ============================================================
#define EEPROM_ADDRESS_MODE        0
// 1 while a step-array mode is running, written back to 0 only by a clean
// terminate() or cancel(). If this is still 1 at boot, the Arduino restarted
// mid-cycle (most likely a relay-module brown-out) instead of finishing
// normally — see e_reprise.ino.
#define EEPROM_ADDRESS_CYCLE_FLAG  1
// Index of the last step reached before the interruption (diagnostic only)
#define EEPROM_ADDRESS_CYCLE_STEP  2

// ============================================================
// Data types
// ============================================================

// One step in a wash sequence: a valve configuration and its duration in seconds
typedef struct step_s {
  unsigned int  config;
  unsigned long duration;
} step_t;

// A named wash mode and its associated step array. `steps` points into
// flash (PROGMEM) — always read it via read_step() (a_donnees_modes.ino),
// never dereference it directly.
typedef struct mode_s {
  const char *name;
  const step_t *steps;
} mode_t;

// Explicit forward declaration. Arduino's automatic prototype generator
// has documented bugs when a function's signature uses a custom struct
// typedef and the function itself is defined in a secondary .ino tab —
// see arduino/arduino-cli issues #2696 and #2946. read_step() (defined
// in a_donnees_modes.ino) is the only function in this sketch affected,
// since it's the only one taking/returning step_t. Declaring it here,
// right after step_t itself, sidesteps the bug entirely.
step_t read_step(const step_t *steps, int index);

// ============================================================
// State machine
// ============================================================
typedef enum state_e {
  STATE_SELECT,         // Enter selection screen
  STATE_SELECT_UPDATE,  // Poll encoder and button on selection screen
  STATE_RUN,            // Initialise and start the selected mode
  STATE_RUN_UPDATE,     // Advance through steps and update display
  STATE_TERMINATE,      // Sequence completed normally
  STATE_CANCEL,         // Sequence aborted by the operator

  // Shown at boot only, if the previous cycle never reached a clean exit
  STATE_RESUME_WARNING,         // Display the interrupted-cycle warning
  STATE_RESUME_WARNING_UPDATE   // Poll button to acknowledge and clear the flag
} state_t;

// ============================================================
// MODES[] is defined in a_donnees_modes.ino (a later tab). This forward
// declaration is what lets setup() below reference MODES_NUMBER despite
// that — see the header comment for why this is the one place in the
// whole sketch that needs it.
// ============================================================
extern const int MODES_NUMBER;

// ============================================================
// Hardware objects
// ============================================================
RotaryEncoder menuselect(PIN_MENUSELECT_1, PIN_MENUSELECT_2);
Bounce buttonAction = Bounce();
LiquidCrystal_I2C lcd(DISPLAY_I2C_ADDRESS, 16, 2);

byte CHAR_UP_DOWN_SETUP[] = {
  B00100,
  B01010,
  B10001,
  B00000,
  B00000,
  B10001,
  B01010,
  B00100
};

// ============================================================
// Global runtime variables
// ============================================================
state_t state = STATE_SELECT;

int           mode = 0;          // Index of the currently selected mode
unsigned long mode_start_time;   // Timestamp (s) when the mode started
unsigned long mode_full_time;    // Total duration of the current mode in seconds

int           step;              // Index of the current step within the mode
unsigned long step_start_time;   // Timestamp (s) when the current step started

// Tracks the previously active valve configuration, so controls_set()
// (c_actionneurs.ino) can compute minimal open/close transitions.
unsigned int previous_config = 0;

// ============================================================
// Arduino entry points
// ============================================================

void setup()
{
  // Pre-drive all relay pins HIGH before configuring them as outputs.
  // This prevents the brief LOW glitch that would otherwise energise
  // relays at power-up and avoids an inrush current spike.
  digitalWrite(PIN_VALVE_AIR, HIGH);
  digitalWrite(PIN_VALVE_CO2, HIGH);
  digitalWrite(PIN_VALVE_WATER, HIGH);
  digitalWrite(PIN_VALVE_CLEANER_IN, HIGH);
  digitalWrite(PIN_VALVE_SANITIZER_IN, HIGH);
  digitalWrite(PIN_VALVE_CLEANER_OUT, HIGH);
  digitalWrite(PIN_VALVE_SANITIZER_OUT, HIGH);
  digitalWrite(PIN_VALVE_DRAIN, HIGH);
  digitalWrite(PIN_PUMP, HIGH);

  pinMode(PIN_BUTTON_ACTION, INPUT_PULLUP);
  pinMode(PIN_VALVE_AIR, OUTPUT);
  pinMode(PIN_VALVE_CO2, OUTPUT);
  pinMode(PIN_VALVE_WATER, OUTPUT);
  pinMode(PIN_VALVE_CLEANER_IN, OUTPUT);
  pinMode(PIN_VALVE_SANITIZER_IN, OUTPUT);
  pinMode(PIN_VALVE_CLEANER_OUT, OUTPUT);
  pinMode(PIN_VALVE_SANITIZER_OUT, OUTPUT);
  pinMode(PIN_VALVE_DRAIN, OUTPUT);
  pinMode(PIN_LED, OUTPUT);
  pinMode(PIN_PUMP, OUTPUT);
  pinMode(PIN_BUZZER, OUTPUT);

  delay(100);

  digitalWrite(PIN_LED, LOW);
  digitalWrite(PIN_BUZZER, LOW);

  buttonAction.attach(PIN_BUTTON_ACTION);
  buttonAction.interval(10);  // Debounce interval in ms

  lcd.init();
  lcd.backlight();
  lcd.createChar(CHAR_UP_DOWN, CHAR_UP_DOWN_SETUP);

  // Restore the last selected mode from EEPROM, clamped to valid range
  mode = EEPROM.read(EEPROM_ADDRESS_MODE);
  mode = constrain(mode, 0, MODES_NUMBER - 1);

  // If the cycle-in-progress flag is still set, the previous run never
  // reached a clean terminate()/cancel() — show the warning instead of
  // silently starting on the normal selection screen.
  if( EEPROM.read(EEPROM_ADDRESS_CYCLE_FLAG) != 0 ) {
    state = STATE_RESUME_WARNING;
  }
}

void loop()
{
  switch(state) {
    case STATE_SELECT:
      select();
      break;
    case STATE_SELECT_UPDATE:
      select_update();
      break;
    case STATE_RUN:
      run();
      break;
    case STATE_RUN_UPDATE:
      run_update();
      break;
    case STATE_TERMINATE:
      terminate();
      break;
    case STATE_CANCEL:
      cancel();
      break;
    case STATE_RESUME_WARNING:
      resume_warning();
      break;
    case STATE_RESUME_WARNING_UPDATE:
      resume_warning_update();
      break;
  }
}

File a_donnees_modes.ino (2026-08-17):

// ============================================================
// Données des modes de lavage
//
// Tableaux d'étapes marqués PROGMEM : ils restent en flash au lieu
// d'être recopiés en RAM au démarrage. On ne les lit jamais directement
// (steps[i].config planterait) — toujours via read_step(), qui copie
// une entrée en RAM avec memcpy_P().
// ============================================================

// Drain sanitizer tank through the keg circuit — 200 s (3 min 20)
const step_t STEPS_DRAIN_SANITIZER[] PROGMEM = {
  {CONFIG_DRAIN_SANITIZER, 200},
  {CONFIG_END, 0}
};

// Drain cleaner tank through the keg circuit — 200 s (3 min 20)
const step_t STEPS_DRAIN_CLEANER[] PROGMEM = {
  {CONFIG_DRAIN_CLEANER, 200},
  {CONFIG_END, 0}
};

// Fill sanitizer tank — 120 s (2 min 00)
const step_t STEPS_FILL_SANITIZER[] PROGMEM = {
  {CONFIG_FILL_SANITIZER, 120},
  {CONFIG_END, 0}
};

// Fill cleaner tank — 120 s (2 min 00)
const step_t STEPS_FILL_CLEANER[] PROGMEM = {
  {CONFIG_FILL_CLEANER, 120},
  {CONFIG_END, 0}
};

// Full wash cycle without CO2 pressurisation — 325 s (5 min 25)
// Reference: https://www.btobeer.com/themes-conseils-techniques-bieres-brasseries/conseils-carbonatation-process-et-analyses/futs-de-biere-a-plongeurs-incorpores-problemes-lies-a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
const step_t STEPS_WASH_KEG[] PROGMEM = {
  // ===== Initial drain =====
  {CONFIG_DRAIN, 10},           // Adjust if needed

  // ===== Initial rinse =====
  {CONFIG_RINCE, 10},
  {CONFIG_RINCE_PURGE, 20},

  // ===== Detergent cycle =====
  {CONFIG_CLEAN, 10},
  {CONFIG_CLEAN_PURGE, 15},
  {CONFIG_CLEAN, 10},
  {CONFIG_CLEAN_PURGE, 15},
  {CONFIG_CLEAN, 10},
  {CONFIG_CLEAN_PURGE, 20},

  // ===== Intermediate rinse =====
  {CONFIG_RINCE, 3},
  {CONFIG_RINCE_PURGE, 10},
  {CONFIG_RINCE, 7},
  {CONFIG_RINCE_PURGE, 10},
  {CONFIG_RINCE, 10},
  {CONFIG_RINCE_PURGE, 20},

  // ===== Sanitization cycle =====
  {CONFIG_SANITIZE, 10},
  {CONFIG_SANITIZE_PURGE, 15},
  {CONFIG_SANITIZE, 10},
  {CONFIG_SANITIZE_PURGE, 15},
  {CONFIG_SANITIZE, 30},        // Adjust if needed
  {CONFIG_SANITIZE_PURGE, 20},

  // ===== Final rinse + air purge =====
  {CONFIG_RINCE, 10},
  {CONFIG_RINCE_PURGE, 30},     // Adjust if needed

  {CONFIG_END, 0}
};

// Detergent-only cycle (no sanitization, no CO2) — 185 s (3 min 05)
const step_t STEPS_DETER_KEG[] PROGMEM = {
  {CONFIG_DRAIN, 10},           // Adjust if needed

  {CONFIG_RINCE, 10},
  {CONFIG_RINCE_PURGE, 20},

  {CONFIG_CLEAN, 10},
  {CONFIG_CLEAN_PURGE, 15},
  {CONFIG_CLEAN, 10},
  {CONFIG_CLEAN_PURGE, 15},
  {CONFIG_CLEAN, 10},
  {CONFIG_CLEAN_PURGE, 20},

  {CONFIG_RINCE, 3},
  {CONFIG_RINCE_PURGE, 10},
  {CONFIG_RINCE, 7},
  {CONFIG_RINCE_PURGE, 10},
  {CONFIG_RINCE, 10},
  {CONFIG_RINCE_PURGE, 20},
  {CONFIG_END, 0}
};

// Full wash cycle with CO2 pressurisation at the end — 335 s (5 min 35)
const step_t STEPS_WASH_KEG_PRESSURIZE[] PROGMEM = {
  // ===== Initial drain =====
  {CONFIG_DRAIN, 10},           // Adjust if needed

  // ===== Initial rinse =====
  {CONFIG_RINCE, 10},
  {CONFIG_RINCE_PURGE, 20},

  // ===== Detergent cycle =====
  {CONFIG_CLEAN, 10},
  {CONFIG_CLEAN_PURGE, 15},

  {CONFIG_CLEAN, 10},
  {CONFIG_CLEAN_PURGE, 15},

  {CONFIG_CLEAN, 10},
  {CONFIG_CLEAN_PURGE, 20},

  // ===== Intermediate rinse =====
  {CONFIG_RINCE, 3},
  {CONFIG_RINCE_PURGE, 10},

  {CONFIG_RINCE, 7},
  {CONFIG_RINCE_PURGE, 10},

  {CONFIG_RINCE, 10},
  {CONFIG_RINCE_PURGE, 20},

  // ===== Sanitization cycle =====
  {CONFIG_SANITIZE, 10},
  {CONFIG_SANITIZE_PURGE, 15},

  {CONFIG_SANITIZE, 10},
  {CONFIG_SANITIZE_PURGE, 15},

  {CONFIG_SANITIZE, 30},        // Adjust if needed
  {CONFIG_SANITIZE_PURGE, 20},

  // ===== Final rinse + CO2 purge + pressurisation =====
  {CONFIG_RINCE, 10},
  {CONFIG_RINCE_PURGE_CO2, 30}, // Adjust if needed
  {CONFIG_CO2, 10},             // Adjust if needed

  {CONFIG_END, 0}
};

// Sanitization-only cycle with CO2 pressurisation — 190 s (3 min 10)
const step_t STEPS_SANITIZE_KEG_PRESSURIZE[] PROGMEM = {
  {CONFIG_DRAIN, 10},           // Adjust if needed

  {CONFIG_RINCE, 10},
  {CONFIG_RINCE_PURGE, 20},

  {CONFIG_SANITIZE, 10},
  {CONFIG_SANITIZE_PURGE, 15},
  {CONFIG_SANITIZE, 10},
  {CONFIG_SANITIZE_PURGE, 15},
  {CONFIG_SANITIZE, 30},        // Adjust if needed
  {CONFIG_SANITIZE_PURGE, 20},

  {CONFIG_RINCE, 10},
  {CONFIG_RINCE_PURGE_CO2, 30}, // Adjust if needed

  {CONFIG_CO2, 10},             // Adjust if needed
  {CONFIG_END, 0}
};

// CO2 pressurisation only — 40 s
const step_t STEPS_KEG_PRESSURIZE[] PROGMEM = {
  {CONFIG_DRAIN, 10},           // Adjust if needed
  {CONFIG_RINCE_PURGE_CO2, 30}, // Adjust if needed
  {CONFIG_CO2, 10},             // Adjust if needed
  {CONFIG_END, 0}
};

// Keg drain + air purge — 70 s (1 min 10)
const step_t STEPS_DRAIN_KEG[] PROGMEM = {
  {CONFIG_DRAIN, 10},           // Adjust if needed
  {CONFIG_RINCE_PURGE, 60},
  {CONFIG_END, 0}
};

// Actuator click-test — 24 s total. Maintenance check, kept in production:
// fires each valve and the pump individually, one at a time, in relay-board
// order (left to right, top to bottom), with a 1 s idle gap between each
// pulse — a quick way to confirm every actuator still clicks and every
// wire is still connected, without running a full wash cycle.
// WARNING: ensure all tanks are empty before running this mode.
const step_t STEPS_TEST_ACTUATORS[] PROGMEM = {
    {CONFIG_WARNING, 5},      // Display safety prompt: confirm tanks are empty
    {CONFIG_WAIT,    1},      // Idle gap

    {CTRL_SANITIZER_OUT, 1},  // Sanitizer return valve
    {CONFIG_WAIT,        1},
    {CONFIG_DRAIN,         1},  // Drain valve
    {CONFIG_WAIT,        1},
    {CTRL_CLEANER_OUT,   1},  // Cleaner return valve
    {CONFIG_WAIT,        1},
    {CTRL_AIR,           1},  // Air inlet valve
    {CONFIG_WAIT,        1},
    {CONFIG_CO2,           1},  // CO2 inlet valve
    {CONFIG_WAIT,        1},
    {CTRL_SANITIZER_IN,  1},  // Sanitizer feed valve
    {CONFIG_WAIT,        1},
    {CTRL_WATER,         1},  // Water inlet valve
    {CONFIG_WAIT,        1},
    {CTRL_CLEANER_IN,    1},  // Cleaner feed valve
    {CONFIG_WAIT,        1},
    {CTRL_PUMP,          1},  // Circulation pump
    {CONFIG_WAIT,        1},

    {CONFIG_END, 0}
};

// ============================================================
// Mode table — order determines rotary-encoder menu order
// ============================================================
mode_t MODES[] = {
  {"Lavage + CO2",    STEPS_WASH_KEG_PRESSURIZE},
  {"Lavage sans CO2", STEPS_WASH_KEG},
  {"Detergent seul",  STEPS_DETER_KEG},
  {"CO2",             STEPS_KEG_PRESSURIZE},
  {"Desinf. + CO2",   STEPS_SANITIZE_KEG_PRESSURIZE},
  {"Vidange fut",     STEPS_DRAIN_KEG},
  {"Vidange desinf.", STEPS_DRAIN_SANITIZER},
  {"Vidange deter.",  STEPS_DRAIN_CLEANER},
  {"Rempl. desinf.",  STEPS_FILL_SANITIZER},
  {"Rempl. deter.",   STEPS_FILL_CLEANER},
  {"Test vannes",     STEPS_TEST_ACTUATORS},
};
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

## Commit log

2026-05-17 negative menu value fix
    [kegwasher.ino]
2026-05-17 fixed relays startup inrush current
    [kegwasher.ino]
2026-05-21 removed CTRL_CO2 and CTRL_DRAIN switch case duplicates
2026-05-25 refactor: code quality improvements and timing fixes
    Type safety
    - step_t.duration: int -> unsigned long (consistent with time arithmetic)
    - mode_start_time, mode_full_time, step_start_time: int -> unsigned long
    - seconds(): return type int -> unsigned long
    - Local time variables in run_update(): int -> unsigned long
    - MODES_NUMBER: mutable int -> const int
    - lcd_printf format specifiers: %d -> %lu for unsigned long operands
    Timing fixes
    - step_start_time recorded AFTER controls_set() in step_set(), so each
    step duration is measured from when the valves are actually in their
    target state, not from before the blocking transitions
    - mode_start_time recorded AFTER step_set(0) i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
    [kegwasher.ino]
2026-05-25 Fix new_mode calculation for encoder position
    Ensure new_mode calculation handles negative positions correctly : modulo always positive, regardless of the amplitude
    [kegwasher.ino]
2026-07-20 Update fill sanitizer and cleaner configurations
    Reverted Gummy35 changes to Vieuxsinge initial configuration because valves "IN" cannot let fluids circulate into the water tanks by conception
    [kegwasher.ino]
2026-07-26 Created documentation
    [kegwasher.fzz]
